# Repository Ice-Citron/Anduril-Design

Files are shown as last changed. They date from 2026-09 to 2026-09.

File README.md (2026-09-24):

# Anduril Design

**[ANDÚRIL RACING — Official team website](https://andurilracing.com/)**

[My personal commentary and project experience](https://sienarindustries.com/project/f1-in-schools)

Car designs, CAD exports, and supporting models for team ANDÚRIL RACING from Marlborough College Malaysia.

## Start here

These are the two main documents for this project. Read the project portfolio first.

1. [Project portfolio](PROJECT_PORTFOLIO.pdf) — Explains our contributions, design decisions, and build process. It covers the car and the wider team project.
2. [Technical drawings and renders](DRAWINGS_AND_RENDERS.pdf) — Shows the assembled car, dimensioned component drawings, and final renders.

*Louis Gan and Shi Hao Ng produced the project portfolio in Adobe Illustrator.*

Pencil sketch of the final ANDÚRIL car

*Pencil sketch of the final car.*

---

### Original sketches

| Initial concepts | Further design ideas |
| --- | --- |
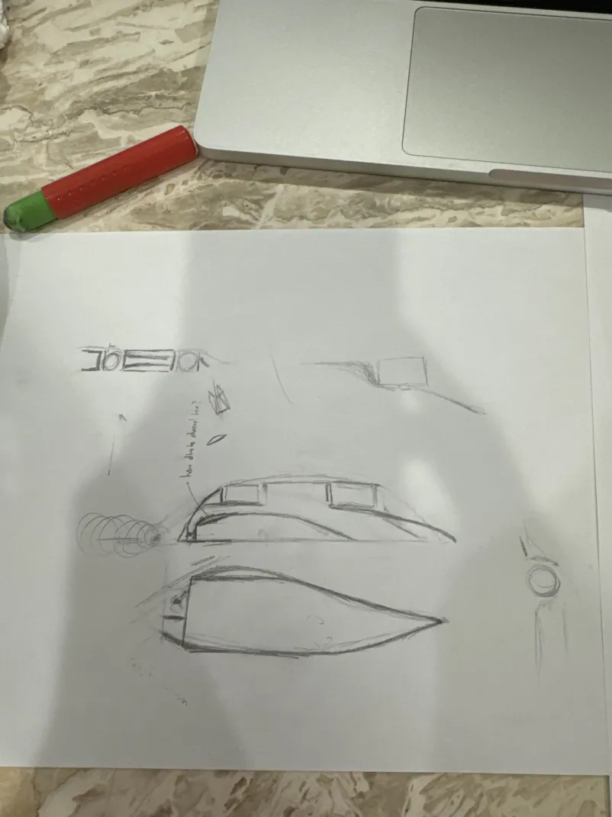
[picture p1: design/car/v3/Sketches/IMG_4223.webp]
Version 3 car sketches
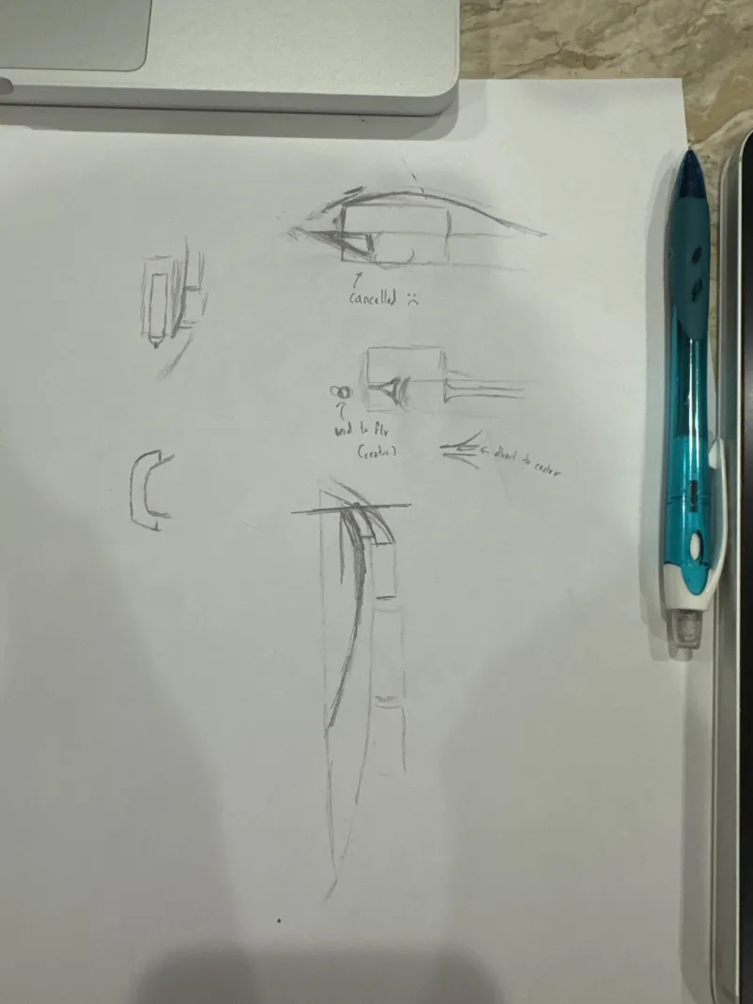
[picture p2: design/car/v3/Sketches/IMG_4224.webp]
Version 3 sketches with design notes
|  |  |

*Early sketches of the body shape and possible airflow paths.*

Full-size scanned drawings:

- [Design sheet 1](<design/car/v3/F1S V3 - 1.jpeg>).
- [Design sheet 2](<design/car/v3/F1S V3 - 2.jpeg>).

[Main project](https://github.com/Ice-Citron/anduril) · [CFD and manufacture](https://github.com/Ice-Citron/Anduril-CFD-and-Manufacturing) · [Team website](https://andurilracing.com)

## About this repository

This repository records the design work behind our F1 in Schools project. It follows the car through five versions, from early Blender models to geometry exports for manufacture and simulation.

I worked on ANDÚRIL as the team and technical lead. The wider project combined car development with a 20 m test track and a team website. This repository contains the design files from that work.

I kept the earlier versions because they show how the design developed. The folders contain sketches, alternative geometries, and intermediate exports alongside the later models.

The files also preserve contributions from other team members. Several revisions retain Louis’s name in their original filenames.

## Car development

The [car design folder](design/car/) contains versions 1–5.

| Version | Contents |
| --- | --- |
| [Version 1](design/car/v1/) | Initial Blender models and a body STL export. |
| [Version 2](design/car/v2/) | Revised Blender models, OBJ files, and component exports for CFD work. |
| [Version 3](design/car/v3/) | Hand sketches, body and wing revisions, and diffuser variants. |
| [Version 4](design/car/v4/) | Further Blender revisions, print geometry, and STEP conversions for CNC manufacture. |
| [Version 5](design/car/v5/) | Later CNC and CFD geometry exports, with STL files for resin checks. |

Start with [Version 5](design/car/v5/) for the later exports. The earlier folders show the design history.

### Version 3 alternatives

Version 3 contains geometry variants with:

- No diffuser.
- A single diffuser.
- A double diffuser.

The [diffuser export folder](<design/car/v3/Diffuser Test - STL/>) keeps these alternatives together.

The sketches record ideas about the car body and airflow. The model files show the subsequent design revisions.

### Blueprints and checks

The [blueprints folder](design/car/blueprints/) contains Blender projects and an STL file under `Fauzi Check/`.

These files sit alongside the numbered versions because the original folder grouped blueprint work and geometry checks.

## Exports for physical models

The [exports folder](exports/) groups files by their intended use.

| Folder | Contents |
| --- | --- |
| [Display models](exports/display-models/) | Car and component exports for the pit display. |
| [Resin prints](exports/resin-print/) | Front-wing and rear-wing STL files. |
| [STL files for STEP conversion](exports/stl-for-step-conversion/) | Component meshes collected for conversion work. |

Version-specific exports remain with their design versions. This preserves the connection between each model and its associated files.

Selected later exports include:

- [Version 5 CNC geometry](<design/car/v5/Export Variant/Version 5 - CNC v3.step>).
- [Version 5 CFD geometry](<design/car/v5/CFD Variant/STEP - UoSM/>).
- [Version 5 resin-check geometry](<design/car/v5/Resin Check - Front Wing + Rear Wing/>).

## Track and pit display

The project extended beyond the car itself.

- [Track design](design/track/) contains the Blender project for the track.
- [Pit-display design](design/pit-display/) contains the Blender project for the display.

The [main repository](https://github.com/Ice-Citron/anduril) contains photographs of the practical work and the wider team project.

## CFD presentation

The [documents folder](docs/cfd/) contains the CFD presentation and the final-car pencil sketch shown at the top of this page.

The [presentation](docs/cfd/F1_mcm.pptx) compares single and double rear vanes in COMSOL 6.1. It includes:

- Model assumptions.
- Mesh illustrations.
- Boundary conditions.
- Drag results over time.
- Flow and pressure visualisations.

The presentation reports slightly lower drag for the single-vane model in that comparison. It also identifies a coarse mesh and simplified flow assumptions as limitations.

The [CFD and manufacturing repository](https://github.com/Ice-Citron/Anduril-CFD-and-Manufacturing) contains the companion simulation and geometry-preparation files.

## Reference materials

The [reference-assets folder](reference-assets/) contains standard component geometry and decals. These assets provided reference geometry alongside our own designs.

The [regulations folder](docs/regulations/) contains the Malaysian State Finals documents from 2024:

- [Competition regulations](docs/regulations/f1_in_schools_Malaysia_competition_regulations_2024_state_finals.pdf).
- [Technical regulations](docs/regulations/f1_in_schools_Malaysia_technical_regulations_2024_state_finals.pdf).
- [View the competition decals](reference-assets/Decal/).

## File formats

| Format | Purpose |
| --- | --- |
| `.blend` | Blender project files. |
| `.blend1` | Blender backup files retained with the projects. |
| `.stl` | Surface-mesh exports. |
| `.step`, `.stp` | CAD geometry exchange. |
| `.obj`, `.mtl` | Mesh geometry and associated material definitions. |
| `.igs`, `.ipt` | Reference component geometry and Inventor part files. |
| `.pptx`, `.pdf` | Presentations and reference documents. |

Open the Blender projects in Blender. Use a compatible CAD application for the geometry exports.

Keep companion files together. For example, the Version 2 OBJ file refers to its adjacent MTL file.

## Repository structure

```text
Anduril-Design/
├── README.md
├── LICENSE
├── .gitignore
├── design/
│   ├── car/
│   │   ├── v1/
│   │   ├── v2/
│   │   ├── v3/
│   │   ├── v4/
│   │   ├── v5/
│   │   └── blueprints/
│   ├── track/
│   └── pit-display/
├── exports/
│   ├── display-models/
│   ├── resin-print/
│   └── stl-for-step-conversion/
├── reference-assets/
└── docs/
    ├── regulations/
    └── cfd/
```

The internal filenames retain the original version labels and contributor references.

## Project walkthrough

I recorded an earlier project walkthrough for Hack Club. Watch from 4:00 to 6:41.

[Watch the walkthrough on YouTube](https://www.youtube.com/watch?v=mP4dqV3jQZ4).

## Related repositories

- [ANDÚRIL main project](https://github.com/Ice-Citron/anduril) — team website, photographs, and sponsorship materials.
- [Anduril CFD and Manufacturing](https://github.com/Ice-Citron/Anduril-CFD-and-Manufacturing) — simulation studies, mesh preparation, and manufacturing geometry.

## Licence

See [LICENSE](LICENSE) for the Apache License 2.0.

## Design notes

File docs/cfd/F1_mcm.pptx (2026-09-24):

## CFD F1 MCM

## Model

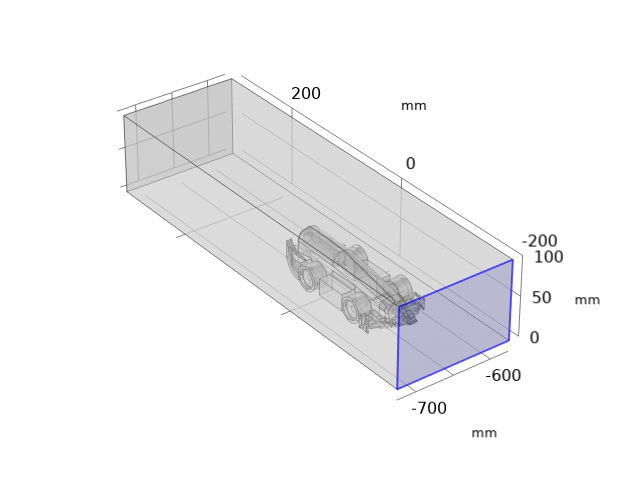
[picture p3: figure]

- Variable
  - Single or double rear vanes

outlet

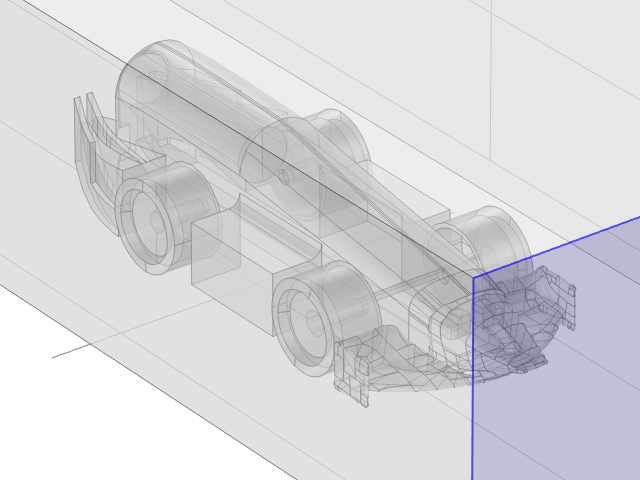
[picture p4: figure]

400 mm

100 mm

inlet

## Assumption

- Tyre fixed
- Cannister is ignored
- Rear wings is removed for simplicity (actually keep facing issue at one surface with bad facets)
- Assuming subsonic – flow is assumed as incompressible

## Mesh

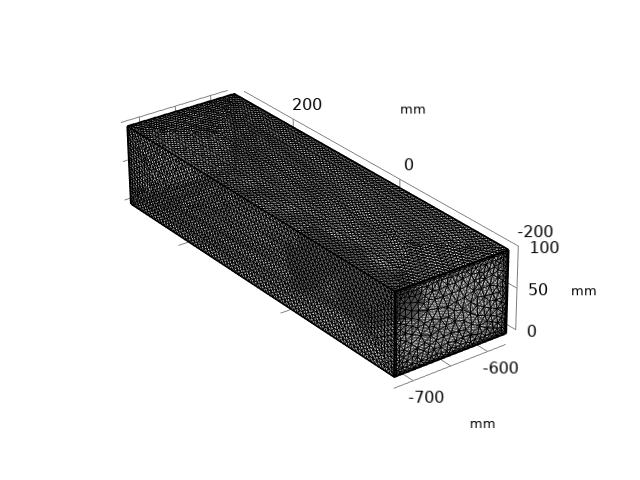
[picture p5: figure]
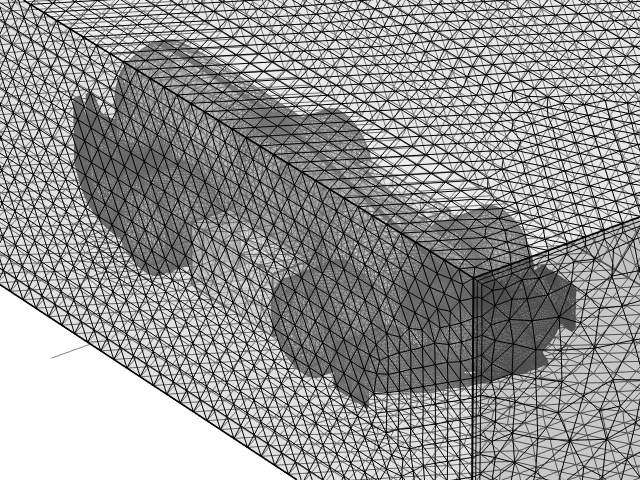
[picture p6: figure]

## Boundary condition

- Inlet – 25 m/s (this is ramped over 1 s)
- Time dependent simulation (Inlet is ramped from 0 to 25 m/s)
- Outlet – zero pressure
- The rest of boundary is set as wall or zero velocity
- Simulation is run in COMSOL 6.1

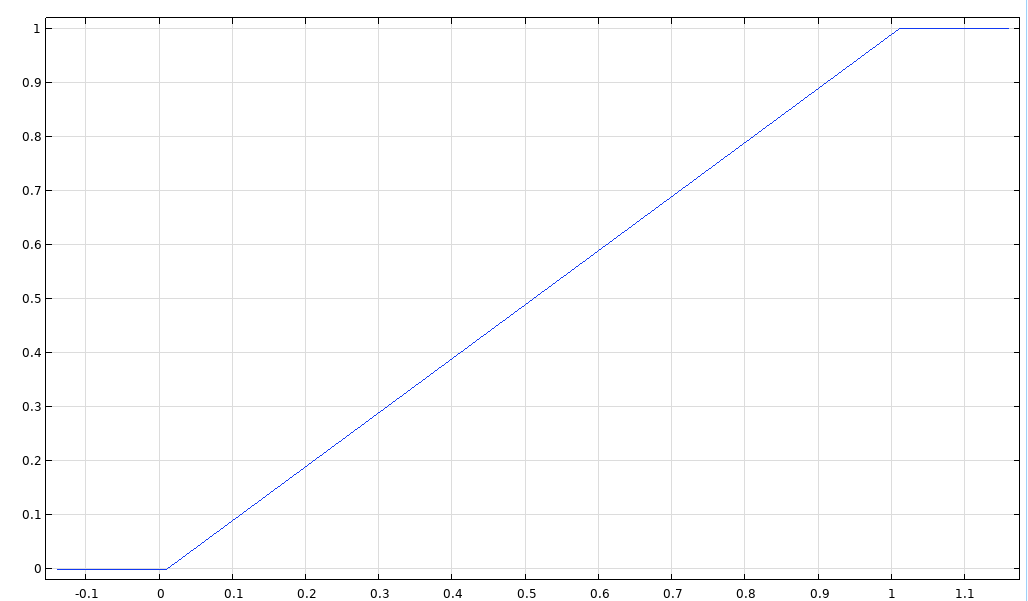
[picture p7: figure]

Inlet velocity (1 is max)

Time (s)

## Result

- Total drag (mN) across time

Time (s) | Inlet Velocity (m/s) | Single Vane (mN) | Double Vane (mN)
0.1 | 2.25 | 1.8056 | 1.6785
0.2 | 4.75 | 3.3874 | 3.5279
0.3 | 7.25 | 5.2954 | 5.5656
0.4 | 9.75 | 7.3611 | 7.6892
0.5 | 12.25 | 9.4996 | 9.8611
0.6 | 14.75 | 11.660 | 12.056
0.7 | 17.25 | 13.826 | 14.262
0.8 | 19.75 | 15.992 | 16.472
0.9 | 22.25 | 18.151 | 18.683
1 | 24.75 | 20.236 | 20.819
1.1 | 25 | 20.501 | 21.088

## Fluid Velocity

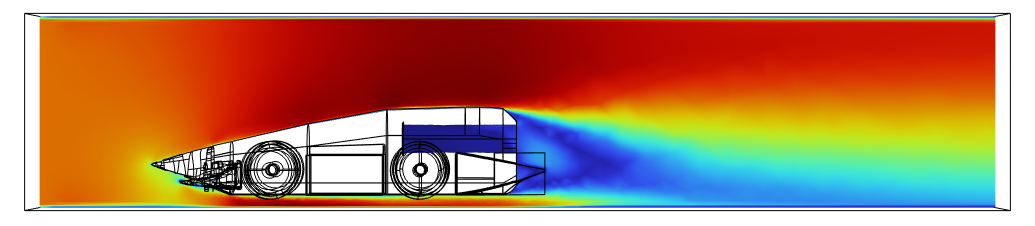
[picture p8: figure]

Single vane

Single vane

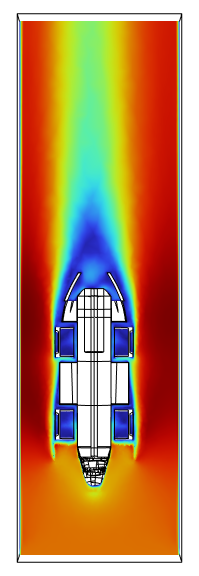
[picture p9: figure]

Double vane

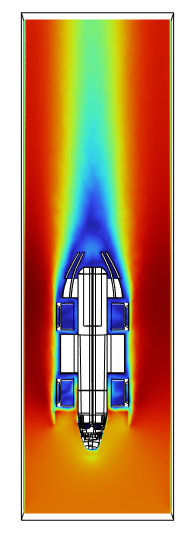
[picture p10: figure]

Double vane

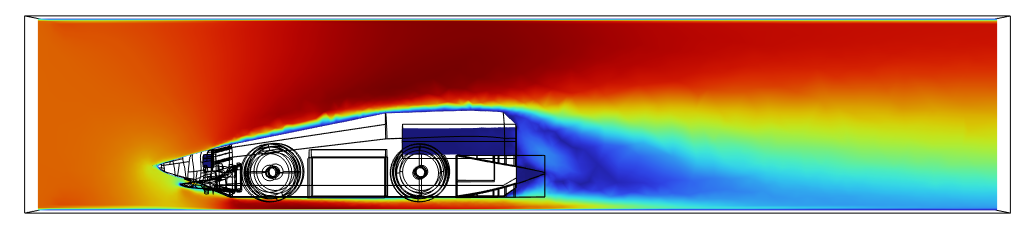
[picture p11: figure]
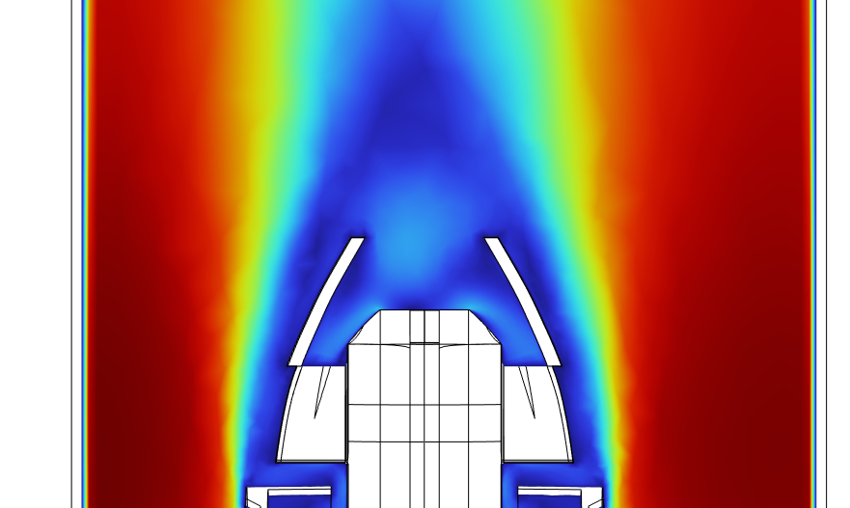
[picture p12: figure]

Single vane

Double vane

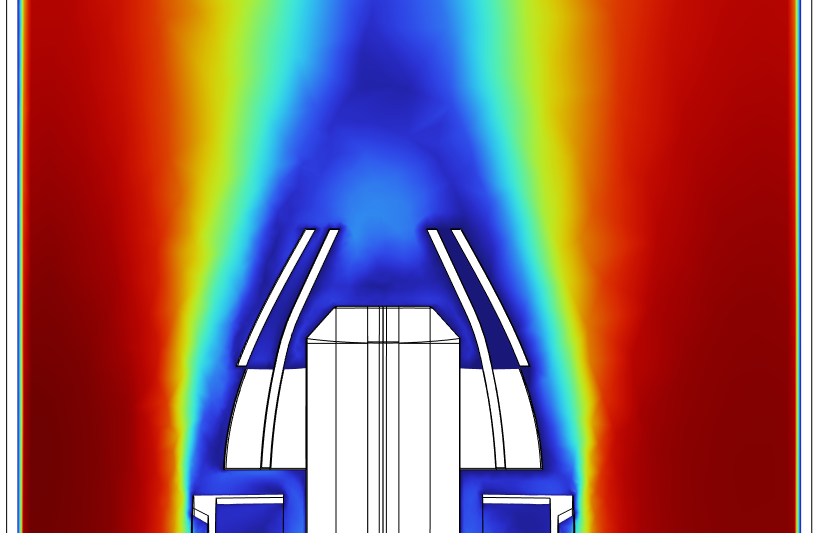
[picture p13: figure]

## Fluid streamline

Single vane

Double vane

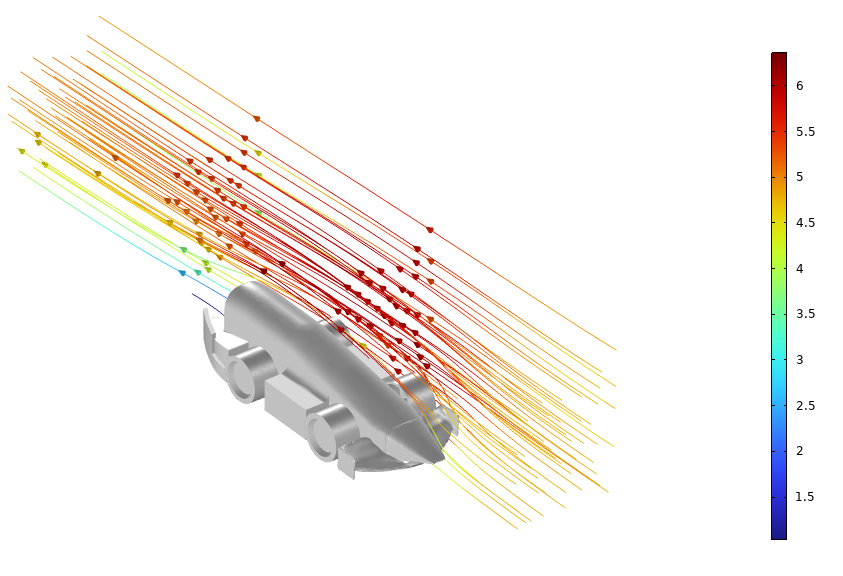
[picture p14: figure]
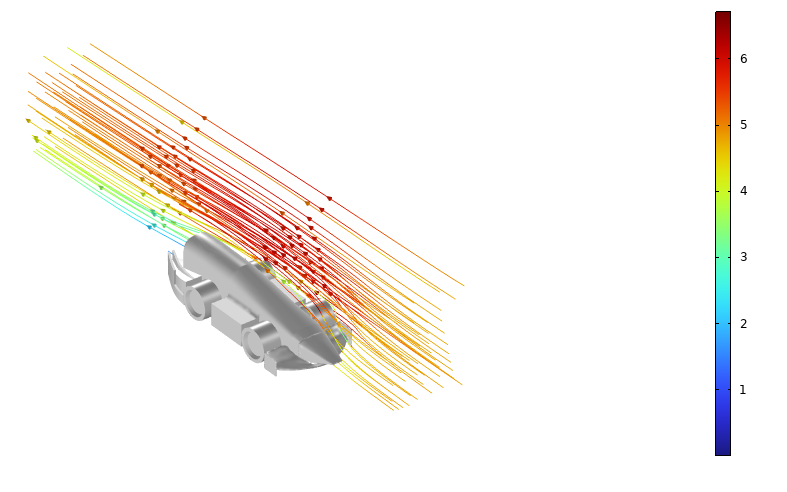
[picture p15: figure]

## Wall shear stress at the rear (Pa)

Single vane

Double vane

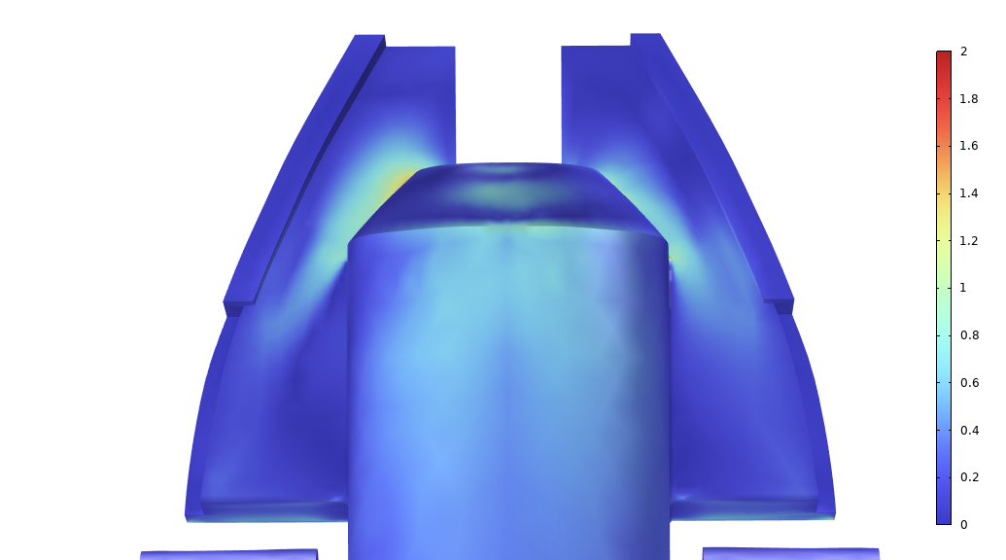
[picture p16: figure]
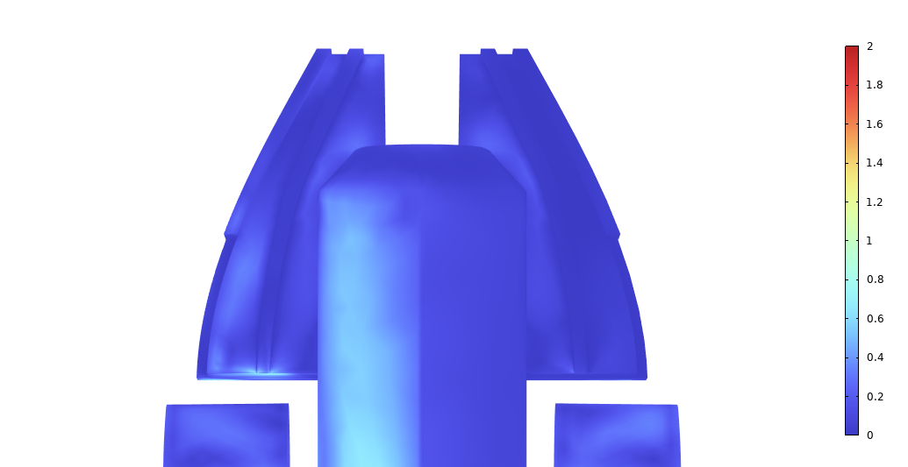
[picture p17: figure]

## Pressure Isosurface (Pa)

Single vane

Double vane

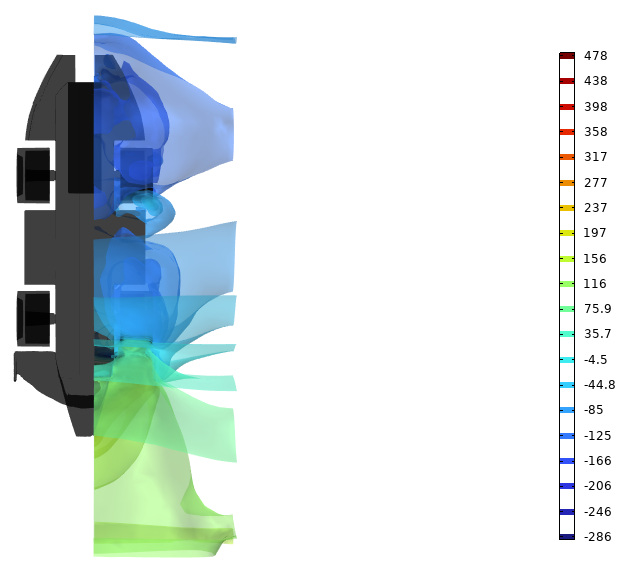
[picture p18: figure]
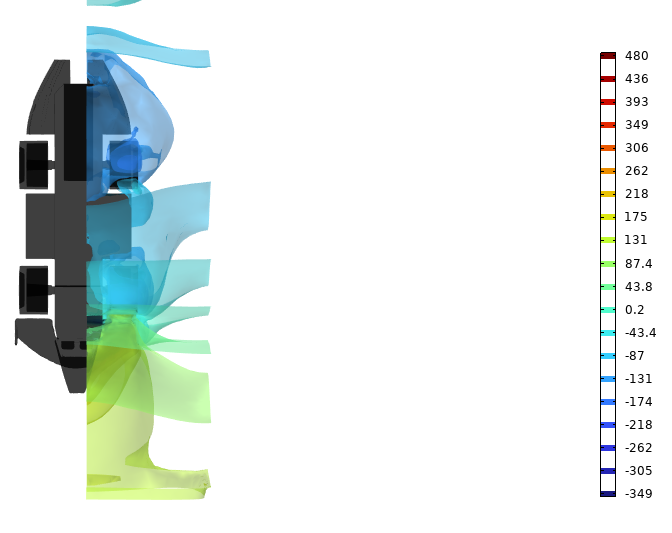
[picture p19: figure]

## Pressure (Pa)

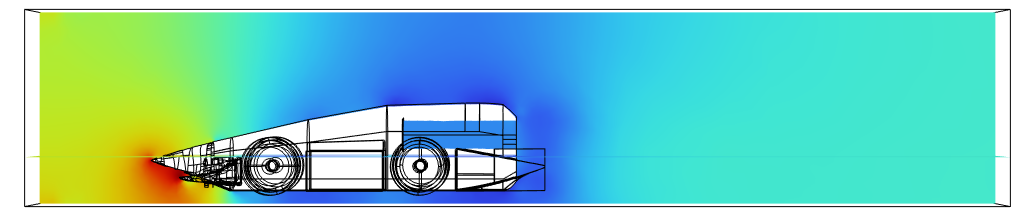
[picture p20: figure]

Single vane

Single vane

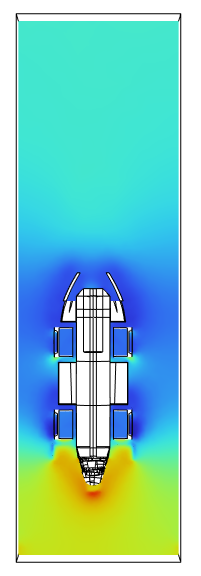
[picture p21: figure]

Double vane

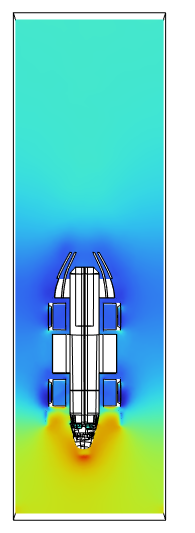
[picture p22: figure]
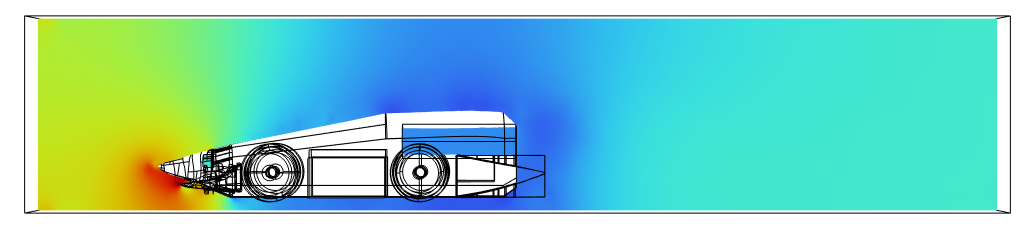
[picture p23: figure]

Double vane

## Comments

- The drag seems to be less in single vane (not by much), probably due to the double vane imposes additional flow resistance.
  - However, the drag is greatly influenced by mesh
- The vanes seems help to orient the pressure so low pressure is nearer to the cannister outlet, which might help to propel the car

## Limitation

- Mesh is quite coarse and some facets issue in the surface between the wings and body, this might affect drag calculations and pressure
  - Normally we would refine the mesh by halving the size 4x to ensure the results no longer change
  - I noticed some parts contains sharp edges, especially in the rear wings, which makes it difficult to import into model,
    - For future work, best to merge all the parts (components) in the CAD, using Boolean operator
- Assumption of no turbulence

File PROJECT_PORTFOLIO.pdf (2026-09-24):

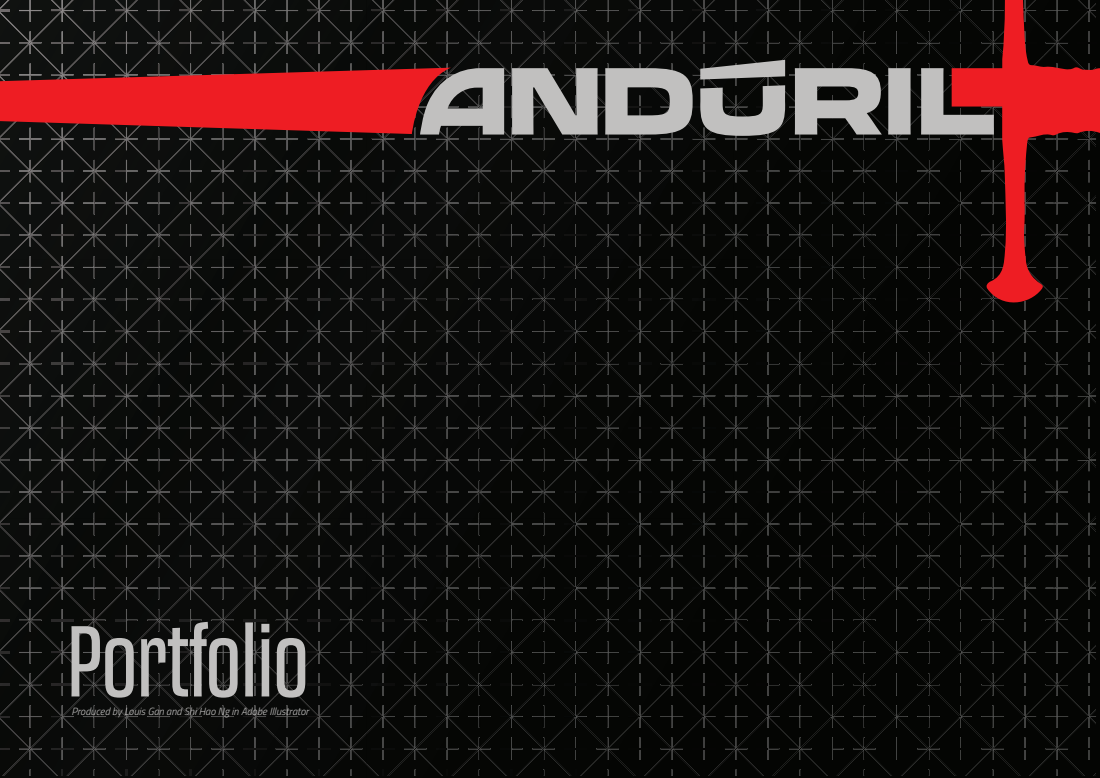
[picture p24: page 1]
Portfolio

Produced by Louis Gan and Shi Hao Ng in Adobe Illustrator

# Research and Development Workflow

Our journey began with Samson and Jane crafting the initial car designs using Blender. Although Blender is primarily an animation software, we chose it for our main CAD modeling due to our team's familiarity with the platform and its ease in translating our concept art into 3D models. These early versions (v1 & v2) were rich in creativity and aesthetics but lacked consideration for the competition's no-go zones and model block size specifications.

# 1 Sketches

With our initial models ready, we proceeded to CFD testing using Ansys Fluent, assisted by University of Southampton Malaysia. Since CFD software requires meshable models, we exported our Blender designs as STL files and converted them to STEP files using the T-Spline function in Fusion 360. These STEP files were then imported into Ansys Discovery for preparation before running simulations in Ansys Fluent. The simulations applied an inlet velocity of 30 m/s and an angular velocity of 2000 rad/s for all 4 wheels to mimic race conditions.

In Version 4, we maintained the long tail design but became more rigorous with regulatory compliance. To meet the no-go zone regulations, we adjusted the entire car forward, allowing us to retain the tail at the car's end while complying with the rules. We meticulously ensured that all aspects of the car met the regulatory requirements.

However, we strategically decided to accept a 5-point penalty related to the front wing chord length (Rule D7.9). Redesigning the front section to comply fully would have resulted in a structurally weaker and less aesthetically pleasing front wing. We deemed the penalty acceptable to maintain the integrity and performance of our design. Most importantly, we ensured that the front wing did not obstruct any other components of the car (e.g. main body).
Due to the increased complexity of Version 4 compared to Version 2, we needed to remesh the STL file using Autodesk Netfabb before converting it to a STEP file with Fusion 360's T-Spline function.

The analysis revealed several weaknesses:
1. Airflow into Wheels: Contour path lines indicated that airflow tended to enter the wheels, creating significant drag. Our per-component analysis showed that the front wing contributed to 70% of the total drag (47.68 mN). Additionally, the wheels, spinning at 2000 rad/s, exacerbated drag due to air bouncing around them.
2. Iso-Pressure Zones: These zones indicated inefficiencies in airflow around the car body, particularly due to the wake of the car. Notable iso-pressure zones were observed behind the front wing, behind the front wheels, and especially at the rear of the car.

Iso-Pressure Zones: These zones (graphed out in image above) indicated inefficiencies in airflow around the car body, particularly due to the wake of the car. Notable iso-pressure zones were observed behind the front wing, behind the front wheels, and especially at the rear of the car.

# 2 Transition to CFD Analysis

# 3 Design Iterations: Version 3

We also introduced air vanes (diverters) to direct airflow to the low-pressure recirculation zone in the rear middle of the car, further minimising turbulence. Concept art for Version 3 was created, showcasing the long tail design and the coverage of both front and rear wheels as much as regulations allowed. We then utilised this concept art directly within Blender to assist in the modelling process.

To address these issues, we focused on minimising the wheels' exposure to airflow. Inspired by the tail design of the McLaren Speedtail, we incorporated a longer tail with a gradual slope behind the rear wheels. This aimed to even out the airflow, reducing turbulence by allowing air to fill the area more gradually, thereby reducing iso-pressure zones at the rear.

Using concept art within Blender to assist in modelling

# 3 Adhering to Regulations: Version 3 Onwards

From Version 3 onwards, we began factoring in the actual model block and no-go zones as specified by the competition rules. We ensured that the front wheels were covered up to a maximum of 20 mm from the bottom of the track and maintained a 3 mm exclusion zone around the wheels, as per the regulations.

To meet no-go zone regulations, we pushed the entire car forward to retain the tail

# Manufacturing

To save money for our school from buying the official expensive Denford Webshop equipments. We took on the ambitious task of manufacturing our own gas launcher, track timer system, and a 20-meter racing track to simulate race conditions accurately.

Our gas launcher was 3D-printed using PLA material, following a design courtesy of @TeachingTech on Printables.com. Key features of the gas launcher include:
- High-Tension Springs: Ensure rapid activation and consistent propulsion of the car.
- Sharpened Screw: Acts as a puncture mechanism for the CO₂ canisters.
- Electric Solenoid Integration: Allows for electronic control through the press of a button, providing precise timing and synchronisation with the timing system (mimicking the official Denford system). After assembly and testing, the gas launcher performed successfully, meeting our requirements for race simulations.

# Gas Launcher

Once the main body and front wing are finalised, we worked on the rear wing. The rear wing was designed primarily for aesthetic purposes and to comply with competition regulations, as additional downforce was unnecessary for a straight-line race. The rear wing features a flat profile cross-section and complements the overall design of the car.
Finally, we sent our finalised design files to Nosco Asia for CNC machining. Concurrently, we used resin printers at UoSM to produce components like the front and rear wings.

We constructed a 20-metre track using pine wood through the following steps:
1. Design: Sketched and designed the track layout in Blender for ease of manufacturing and coordination with the Estates team.
2. Cutting & Sanding: Cut pine wood to required dimensions using a jigsaw and table saw, then sanded with orbital sanders while wearing safety goggles and aprons.
3. Track Connectors: Fabricated joints by modifying stainless steel brackets to securely connect track segments, ensuring safety gear was worn.
4. Assembly: Applied adhesive to join track sections and collaborated with Marlborough College Malaysia’s Estates team to carry and assemble the track and tables.
With assistance from the Estates team, we assembled the track and tables in our designated testing area, repurposing unused old tables from MCM to promote sustainability.
Finishing Touches
We painted the pinewood track to enhance its appearance and protect against Malaysia's humid conditions. Custom decals were added to personalize the track and promote our team branding.

# 20m Track

To accurately measure the performance of our car, our Electronics Engineer prefabricated a track timer system using an Arduino microcontroller paired with laser sensors and photoreceptors. The system was programmed in C++, enabling precise detection of the car's start and finish times, thus allowing us to gather essential data on speed and acceleration.

# Track Timer System

Nosco Asia facilitated our collaboration with a third-party CNC machining service in Larkin, Johor Bahru. Working closely with their team, we built the CAM file based on the STEP file of our final car design.

- CNC Machining: Precisely
cutting the car's body from
the specified material using computer-controlled
equipment. We’ve assisted
the 3rd party provider
“Sticker Shop@Larkins, JB” with Mastercam and
Fusion 360. To guide him
with the process of
machining our car.
- Sanding: Post-machining, we sanded the car's
surface to eliminate any
rough edges or
imperfections.

# 4 Car Manufacturing Final CFD Testing and Improvements

We conducted further CFD tests using the same setup as before. The results showed a significant reduction in drag:
- Version 2 Drag: 47.68 mN
- Version 4 Drag: 29.52 mN (single vane diffuser)
- Version 4 Drag: 30.36 mN (double vane diffuser)
These CFDs conducted using the Comsol fluid modulus indicate a substantial reduction in turbulence. The side profile of the air velocity graphs confirmed that our design modifications effectively minimised turbulence compared to Version 2.

Initially, we designed a triple vane rear diffuser, but material constraints and potential airflow disruptions limited us to single and double vane configurations. A double vane design required vanes only 20mm thick, risking breakage with our polyurethane car body. To mitigate this, we opted for a single vane diffuser with a 30mm thickness for Version 5. Once the design was finalized, we prepared the files for CNC machining and began designing the rear wing.

Cross-sectional profile of Rear Wing

<--- Final Version 5 car with rear wing

Mastercam software. We guided the 3rd party Nosco Asia’s CNC provider over Whatsapp on how to CNC our car, and the
requirements.
- 3D printed front wing: We’ve used the resin printers of University of Southampton to facilitate the printing of our front wings and rear wings.
- Assembly: We’ve used adhesives to attach components such as the front and rear wings.
- Final Painting and Sticker: The car is then spray painted to metallic black. However, applying the sticker will be an outstanding task, as of 2/10/2024. But we will be applying our team colours and sponsorship stickers to align with our branding.
Through this meticulous process, we aimed to produce a car that not only meets the competition's technical specifications but also embodies our team's dedication to excellence in engineering and aesthetics.

Priming and Painting: To prepare the car for painting, we applied six layers of primer, meticulously alternating between spraying and sanding each layer. This iterative process ensured a smooth surface that minimizes the drag coefficient, providing an ideal foundation for the final paint.

# Team Roles & Responsibilities

Project Management
Effective communication and coordination are the backbone of our project management strategy. While each team member has clearly defined roles, flexibility is maintained as members step into different responsibilities when needed to ensure smooth progress and efficiency.
Google Drive: Acts as our centralized repository for all documents, facilitating real-time collaboration and easy access for every team member.
GitHub: Utilized for storing larger files such as CAD models and website code, ensuring robust version control and seamless updates.
Emails: Serve as the primary method for assigning tasks, sharing detailed information, and communicating daily goals. Instant Messaging (Instagram Messages): Preferred during holidays for quick communication. During regular school days, we alternate between Instagram messages and emails based on accessibility and convenience.
Instagram Calls: Employed for emergency meetings and real-time collaboration, especially when team members are working remotely.

Name Background
Our team name, Andúril, is inspired by the legendary sword from The Lord of the Rings. Reforged from the shards of Narsil, Andúril symbolises hope, renewal, and leadership in times of adversity. It serves as a powerful emblem of unity and strength, reflecting our team’s commitment to overcoming challenges and striving for excellence.
Colours
We selected a palette of red, silver, and black to represent our team:
Red: Symbolises passion, energy, and speed, embodying the core values of Formula 1. Silver: Represents precision, technical excellence, and innovation, highlighting our engineering prowess.
Black: Adds contrast and sophistication, enhancing the overall aesthetic of our design. These colours were chosen based on extensive research and a team-wide questionnaire, ensuring they resonate well with our brand and are visually appealing. Team Motto
"Per Aspera Ad Astra"
Our team’s motto, "Per Aspera Ad Astra," embodies the essence of our journey and aspirations in the F1 in Schools competition. This Latin phrase translates to "Through Hardships to the Stars," reflecting our commitment to overcoming challenges and striving for excellence in every aspect of our project.
Uniform
Our team uniforms are designed to showcase both unity and our brand identity. Key considerations in the design include:
Clear and Memorable Branding: Ensures our team is easily identifiable. Professional Appearance: Reflects our values of excellence and dedication. Strategic Placement of Sponsor Logos: Guarantees visibility and return on investment for our sponsors. Comfort and Suitability: Designed to be worn comfortably in Malaysia’s humid climate, ensuring team members can perform optimally.

Gantt Charts (Google Sheets): Used to outline task expectations and deadlines, providing a clear timeline and efficient progress tracking. Our Gantt Charts include:
Job Descriptions: Clearly define each task and responsibility.
Job Status: Track the progress of each task.
Time Remaining: Monitor deadlines to ensure timely completion. Potential Safety Risks: Identify necessary Personal Protective Equipment (PPE) for each task. Risk of Timeline Delays: Assess the likelihood of delays and prepare backup plans. For example, on October 2, 2024, when Jolie fell ill last minute, causing a portfolio submission delay, we activated our backup plan by adjusting our schedule the following day to accommodate the change.
Expense Tracking (Excel Sheets): Managed all expenses and finances using Excel sheets, ensuring transparent and accurate financial oversight.

In-Person
Meetings:
Conducted for
group work and
tackling complex
tasks, leveraging
the productivity
and clarity of
face-to-face
interactions.

### Our team, Andúril Racing, is composed of six dedicated members, each bringing unique skills to the table:

### Shi Hao Ng: Project Manager & General Engineer –

Oversees project coordination with all stakeholders,

### technical lead for CFD and car design, and manages

track manufacturing tasks.

### Louis Gan: Electronics Engineer & Lead Graphic Designer – Designer for brand identity such as logos, merchandise and banners, and develops

electronic systems for testing the car.

### Samson Hong: Design Engineer – Leads the car manufacturing and CAD modelling process, and

ensures high quality Blender animation & rendering.

### Jolie Teo: Web Designer & Graphics Designer – Develops and maintains our team’s website and creates graphics materials, also assisting in

manufacturing and sponsorships.

### Hengjun Tian: CFD Engineer & Manufacturer – Conducts Computational Fluid Dynamics (CFD) with Ansys Fluent and implements the track

manufacturing process.

### Jane Ng: Concept Artist & Sponsorship Manager – Creates concept art for car and manages

sponsorship outreach and relationships.

# About Us

Emails: The project manager often Team Identity reaches out to teammates to

distribute work and to communicate
what each member should get done
for the day.
We purchased custom email domains for our team for a streamlined electronic mail experience as well as a professional look when sending sponsorship requests via email. Typography
Our chosen font, Transducer Extended Bold, conveys
confidence and power. Its
streamlined design mirrors the sleek form of Formula 1 cars, emphasising precision and high-tech performance. The metallic texture of the font enhances its high-tech, engineered aesthetic,
aligning seamlessly with the advanced dynamics of
racing.
The Andúril logo features
the team name seamlessly
integrated along a sword
blade, symbolising the unity between our team and its
legendary inspiration.

# Partnership and Sponsorship

Our partnership with the University of Southampton Malaysia allowed us to use their program “Ansys Fluent” to test our F1 in car’s model’s movement and design. Their research assistance not only helped us save funds but also time. They had also provided us with resin printing equipment, which helped our production of the actual car.

## Return on Investment

We have laid a strong foundation for future participants in F1 in Schools, not just at MCM, but in Johor. By building our own track, gas launcher and electronics timer system, we saved the school approximatelyMYR 42,000, excluding 30% import duties and taxes. Considering their sponsorship of just MYR 6,000, this is a substantial return on investment for Marlborough College Malaysia. Most importantly, we firmly believe that, because of us, because of our manufacturing of the track, gas launcher, and track timer system. We had laid out a
strong foundation for many future teams from MCM
to join the F1 in Schools programme.

Nosco Asia Sdn Bhd played a crucial role in our manufacturing and marketing strategies. They facilitated our collaboration with a CNC machining service in Larkin, Johor Bahru, ensuring precise production of our car components. Nosco Asia also provided banner printing services and transportation support, which significantly boosted our marketing efforts and outreach campaigns. They had sponsored us 3,200 MYR for the banner printing and the CNC machining services.

We worked on the business aspects with UoRM and most of these include the sponsorship proposal. Although our sponsorship proposal wasn’t as successful as we wished for it to be (as we only managed to receive Nosco Asia’s support), we wish to flesh it out further and try out a different technique for the nationals. They had also helped us with project management after advising our project manager to try “Gantt Chart” to distribute tasks and communicate deadlines; and dealing with issues such as conflict between team members; also when we were forced to remove a member due to the severe lack of contribution.

Our school, Marlborough College Malaysia (MCM), has been our main sponsor for all of our respective expenses of up to 6k MYR. MCM supported us in many different ways, including providing old desks for our track, allocating estate staff to assist in track manufacturing and moving equipment from one building to another. MCM also allowed us to display banners across the school to advertise. In return, we built a race track and an efficient timing system which is open to any schools established in Johor (to encourage new F1 in schools participants in Johor). Additionally, by reusing desks that were set to be scrapped, we contributed to reducing waste and reusing materials.

To enhance our design's aerodynamic efficiency, we attended courses with Professor Azam Bakir at the University of Southampton Malaysia (UoSM). These sessions provided a foundational understanding of the Navier-Stokes equations and fluid dynamics principles. Recognizing that solving Computational Fluid Dynamics (CFD) simulations analytically is impractical for complex designs, we agreed with Professor Bakir's assessment to focus on computational methods and fluid flow theories. Concepts such as how holes lead to suction and how low-pressure zones lead to turbulence became central to our design considerations.

YOUR
LOGO
HERE

AD
PLACE
MENT

COMPANY
PARTNERSHIP

YOUR
LOGO
HERE

AD
PLACE
MENT

COMPANY
PARTNERSHIP

We have also created a website summarising details regarding our team members, summarising our sponsors and answering any questions regarding F1 in schools and our team.
We felt that creating a website can create memorable credentials with companies and schools who may wish to sponsor us but are confused as to what Anduril Racing stands for.

Our social media endeavours ranged from Instagram, later to Linkedin (to establish a professional identity for Anduril Racing) and lastly, Facebook. Our strategy begins with reaching out to familiar faces : we followed familiar people such as our family members, then our relatives, schoolmates and lastly, accounts that are associated with f1. We can help to build awareness on Anduril Racing’s participation in F1 in schools and hence potentially gain partnerships. Social media was also a great way of allowing our partners to keep track of Anduril Racing’s activities and recent goals.

To advertise Anduril Racing, three of our members went on to hike Mount KInabalu and spread the word regarding Anduril Racing’s participation in the competition (to different hikers that we met along the way). Many of our fellow hikers still check on our Instagram till this day.

# ခandurilracing.com

## Mount Kinabalu Teambuilding & Mountain Climbing Trip (4095m)

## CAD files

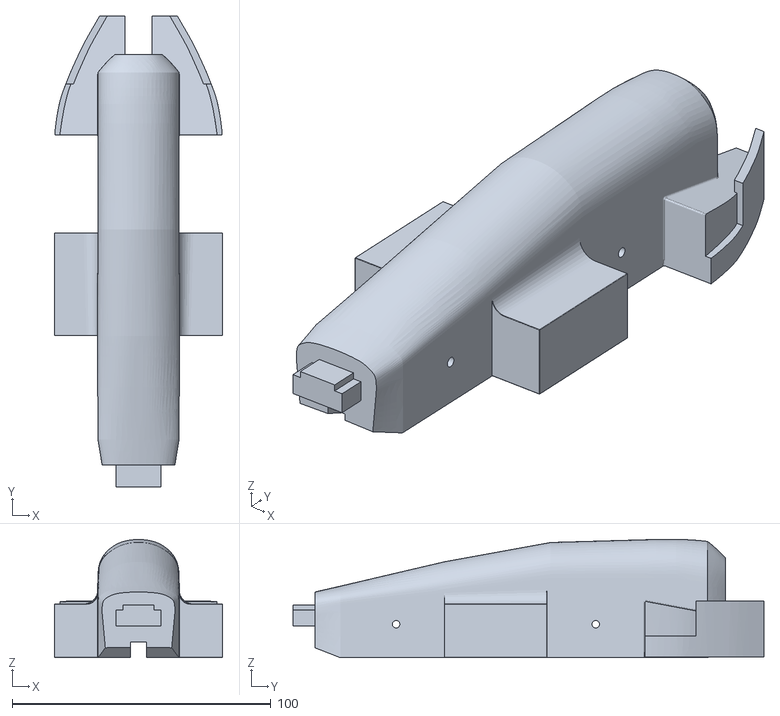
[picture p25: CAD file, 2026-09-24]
design/car/v5/Resin Check - Front Wing + Rear Wing/MAIN_Body1.stl
65.0 x 181.9 x 45.6

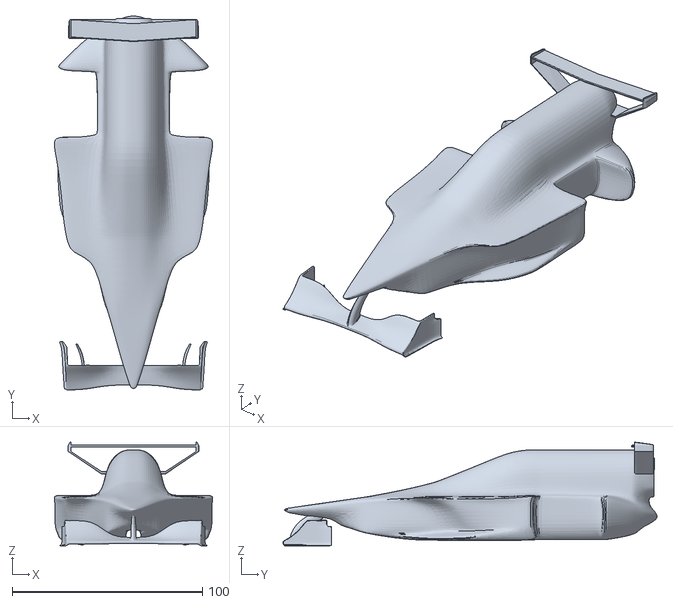
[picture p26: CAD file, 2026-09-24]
exports/display-models/Version 2/Ver. 2-ASSEMBLE BODY.stl
83.2 x 196.6 x 54.6

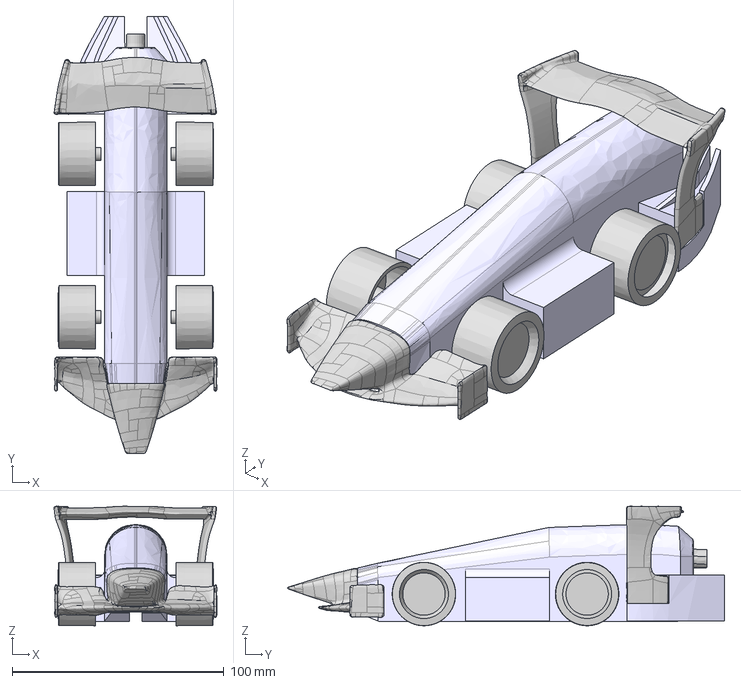
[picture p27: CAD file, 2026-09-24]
design/car/v5/CFD Variant/STEP - UoSM/Version 5 - CFD 2mm double v2.step
77.0 x 206.6 x 56.5 mm

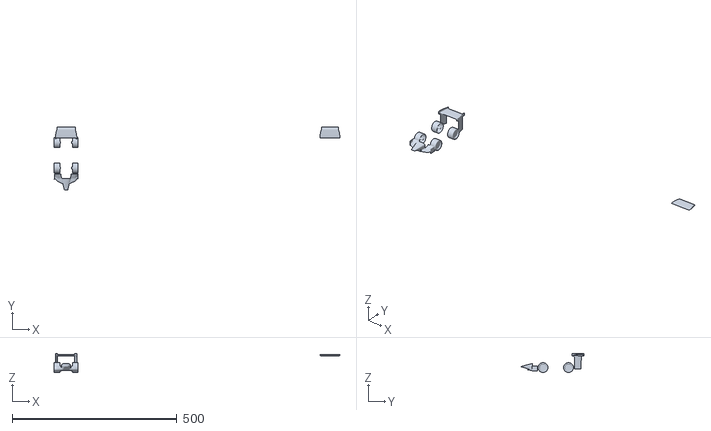
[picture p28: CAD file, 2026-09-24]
design/car/v5/CFD Variant/Version 4 - Print-Rear Wing.002.stl
867.0 x 192.3 x 57.7

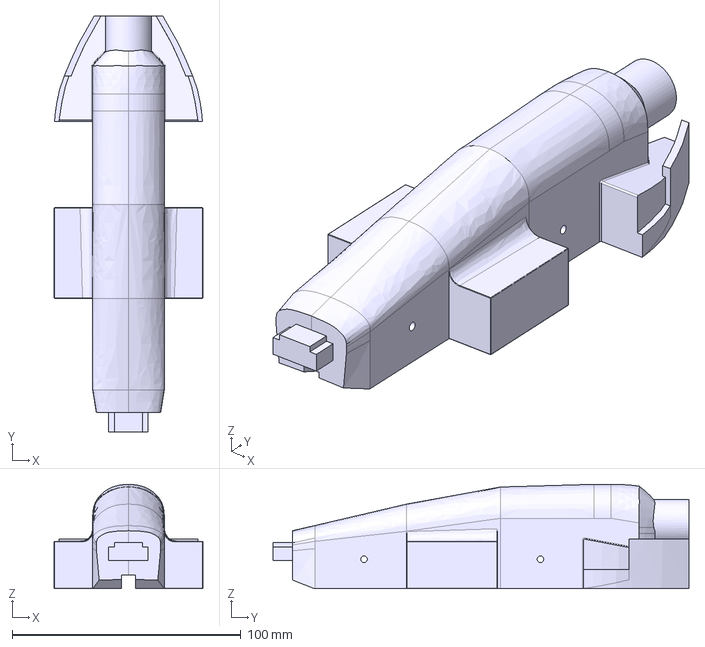
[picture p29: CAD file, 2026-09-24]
design/car/v5/Export Variant/Version 5 - CNC v3.step
65.0 x 181.9 x 45.6 mm

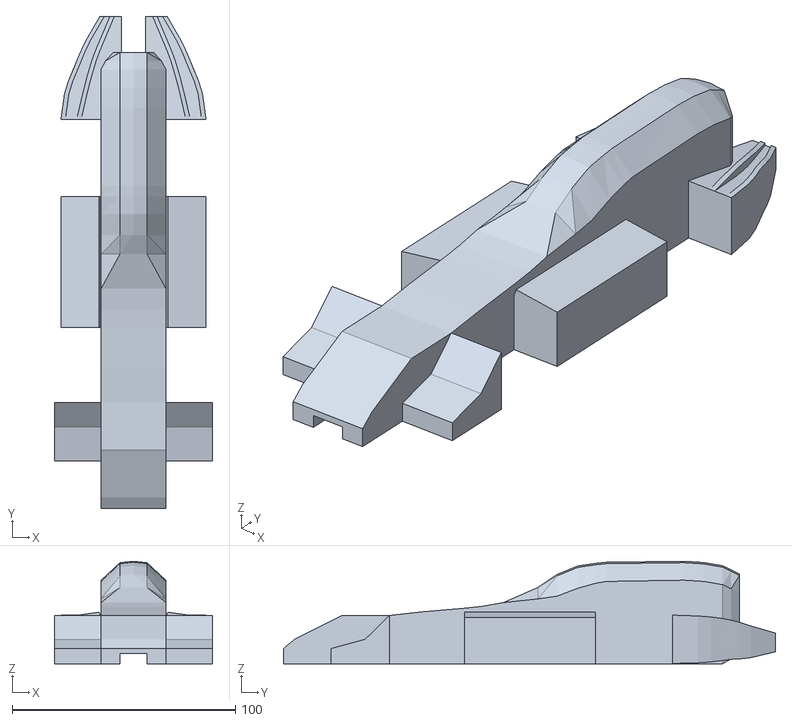
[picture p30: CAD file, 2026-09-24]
exports/display-models/Maybe/Version 3-Version 3.stl
70.7 x 220.3 x 45.9

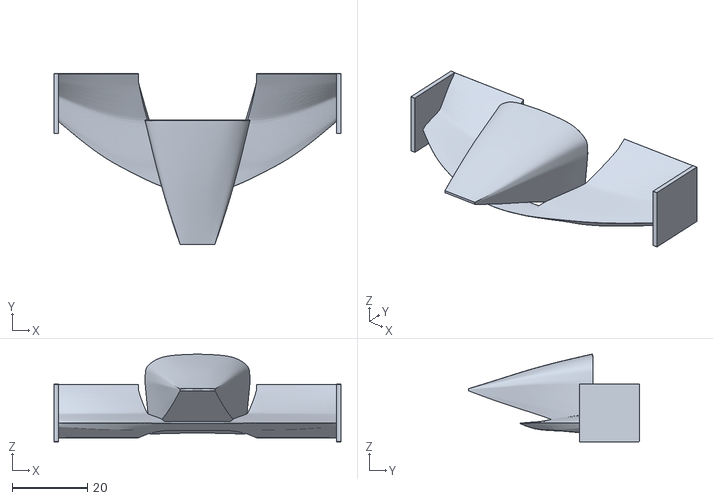
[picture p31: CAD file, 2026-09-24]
exports/resin-print/Blueprint and STL-FRONT WING Version 3.011.stl
76.5 x 45.5 x 23.3

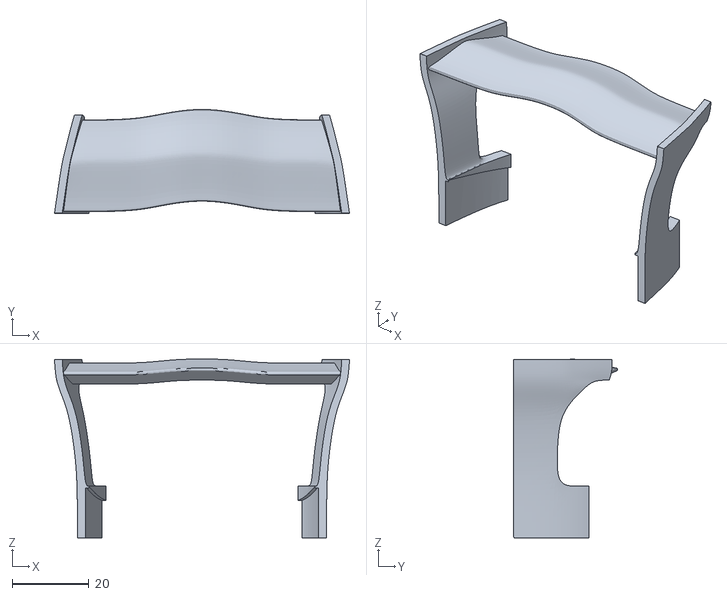
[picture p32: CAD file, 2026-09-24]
exports/stl-for-step-conversion/Blueprint and STL-Rear Wing - flaps.010.stl
77.0 x 27.2 x 46.7

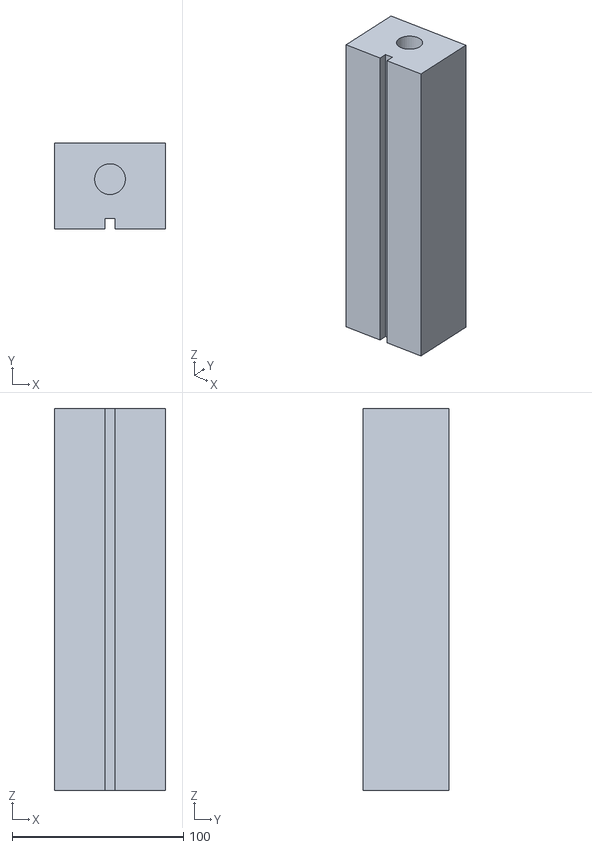
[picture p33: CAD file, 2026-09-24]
reference-assets/F1 Model Block/f1_model_block_18mm.stl
65.0 x 50.0 x 223.0

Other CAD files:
exports/display-models/Single/Blueprint and STL-MAIN_Body1.stl
design/car/v5/Version 5 - Checking.stl
exports/display-models/Double/Blueprint and STL-Version 3.009.stl
design/car/v1/Ver-1-ASSEMBLE BODY.stl
design/car/v1/Ver-1.blend
design/car/v1/Ver.1.blend
design/car/v2/Archive/Ver-2-new.blend
design/car/v2/Original/Ver. 2.blend
design/car/v2/STL FILES/Ver-2-new-ASSEMBLE BODY.stl
design/car/v2/STL FILES/Ver-2-new.obj
design/car/v2/STL FILES/Ver. 2-Cube.stl
design/car/v2/STL Files - CFD/Archive - Trail 1/Ver-2-new-Axle Rod.stl
design/car/v2/STL Files - CFD/Archive - Trail 1/Ver-2-new-Cube.stl
design/car/v2/STL Files - CFD/Archive - Trail 1/Ver-2-new-Front Wing.stl
design/car/v2/STL Files - CFD/Archive - Trail 1/Ver-2-new-REAR WING.001.stl
design/car/v2/STL Files - CFD/Archive - Trail 1/Ver-2-new-REAR WING.stl
design/car/v2/STL Files - CFD/Archive - Trail 1/Ver-2-new-f1_wheel.stl
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

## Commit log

2026-09-24 [Personal Documentations]: Rearranged all files to appropriate readable structure.
    [20240919_VERSION4_update.stp, 2mm - Blueprint and STL-Rear Wing - flaps.005.stl, Axle Bush.step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]
2026-09-24 [Personal Documentations]: Minor staged README change.
